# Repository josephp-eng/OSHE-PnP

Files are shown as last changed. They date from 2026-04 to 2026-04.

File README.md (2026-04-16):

# OSHE Pick and Place (V2.0)





<div align="center">

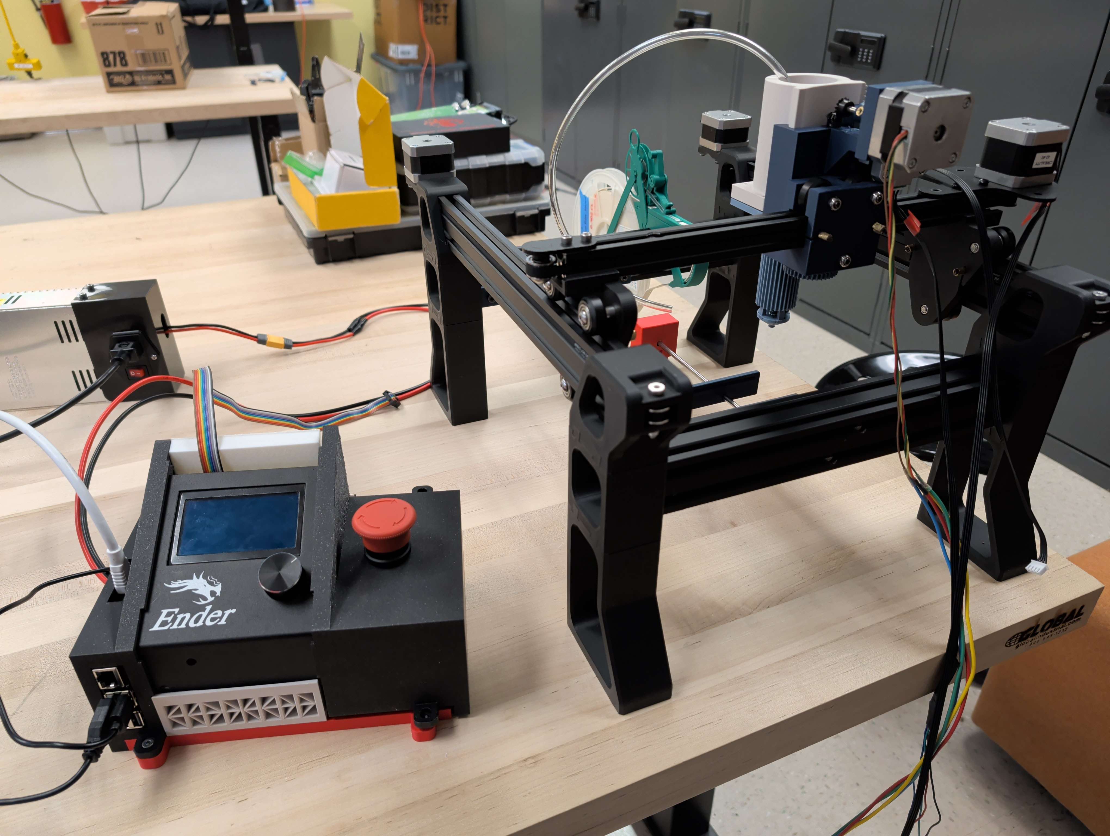
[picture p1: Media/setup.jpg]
Physical Model


</div>

## 🎯 Summary

The **OSHE Pick-and-Place** is a low-cost, open-source automated PCB assembly system developed at Michigan Technological University. While industrial SMT solutions are often financially out of reach for small labs and hobbyists, this project provides a modular, 3D-printable framework optimized for performance and ease of assembly. 

The system leverages the mechanical foundations of a Creality Ender 3, extending its capabilities into a dedicated manufacturing tool. By utilizing a vacuum-based toolhead and precision motion control, this project bridges the gap between manual prototyping and industrial production.

### 🛠️ Core Technical Achievements
* **Precision Motion Control:** Migrated to **Klipper Firmware** via Mainsail OS, allowing for higher-speed pathing and web-based machine management.
* **Advanced Toolhead Design:** A custom-engineered 3D-printed assembly featuring full 360° rotation and an integrated vacuum pick system.
* **Expanded Work Envelope:** Features a 370 x 480 mm footprint and support for PCBs up to 250 x 250 mm.
* **Safety-First Integration:** Adheres to **ISO-12100 standards**, featuring dedicated emergency stop (E-Stop) hardware and passive shielding.

### 📈 Current Project Status
The Spring 2026 revision (V2.0) has successfully transitioned the project into a functional integration phase. The machine currently supports SMD components (0804 and larger). Future development focuses on integrating computer vision and automated reel loading.
This project currently exists separately from the OpenPnP architecture. It was not designed around their software suite.

---

## 📂 Project Documentation

> [!IMPORTANT]
> For the complete technical breakdown, including assembly guides and safety protocols, refer to the full master document below.

* **[📄 Full Technical Manual](https://docs.google.com/document/d/1zdPMhOE8R7Szz68Ky9EoDyxVyp7iftD7q8Uco1WKPY8/edit?usp=sharing)** - Detailed assembly, electrical, and safety documentation.
* **[📦 Bill of Materials (BOM)](https://docs.google.com/spreadsheets/d/12Wk4rjcJYJA1_MIOu3757zk9U3lGuzmtH0hi1Tlr5gI/edit?usp=sharing)** - Comprehensive Google Spreadsheet lists of hardware, electronics, and 3D-printed parts.
* **[⚙️ Configuration Files](Software/Klipper)** - `printer.cfg` and macro definitions for Klipper.
* **[📐 CAD & Model Files](CAD)** - Full assembly models and printable components.

---

## 📋 Repository Structure
* `/CAD`: STEP and STL files for the machine and custom components.
* `/Software`: Klipper configurations and legacy Marlin firmware.
* `/Archive`: Legacy V1 designs and research notes.
* `/Media`: Renders and isometric views of models.
* `/BOMs`: Subsystem bills of materials, including hardware and 3D printed components.

## 💻 Getting Started
1. Review the [Our Documentation](https://docs.google.com/document/d/1zdPMhOE8R7Szz68Ky9EoDyxVyp7iftD7q8Uco1WKPY8/edit?usp=sharing) for the full build guide. Follow along with the 3D printing settings outlined in [CAD]([link](https://github.com/OSHE-Github/OSHE-PnP/tree/main/CAD))
2. Clone this repo to access the latest Klipper `printer.cfg`.
3. Join the conversation on the [OSHE Website]([link](https://oshe.io/)) and check out other OSHE projects at our [enterprise GitHub](https://github.com/OSHE-Github)

---
*Developed under the Michigan Technological University Open Source Hardware Enterprise (OSHE)*

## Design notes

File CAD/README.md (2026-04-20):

# Pick and Place CAD Documentation

<div align="center">

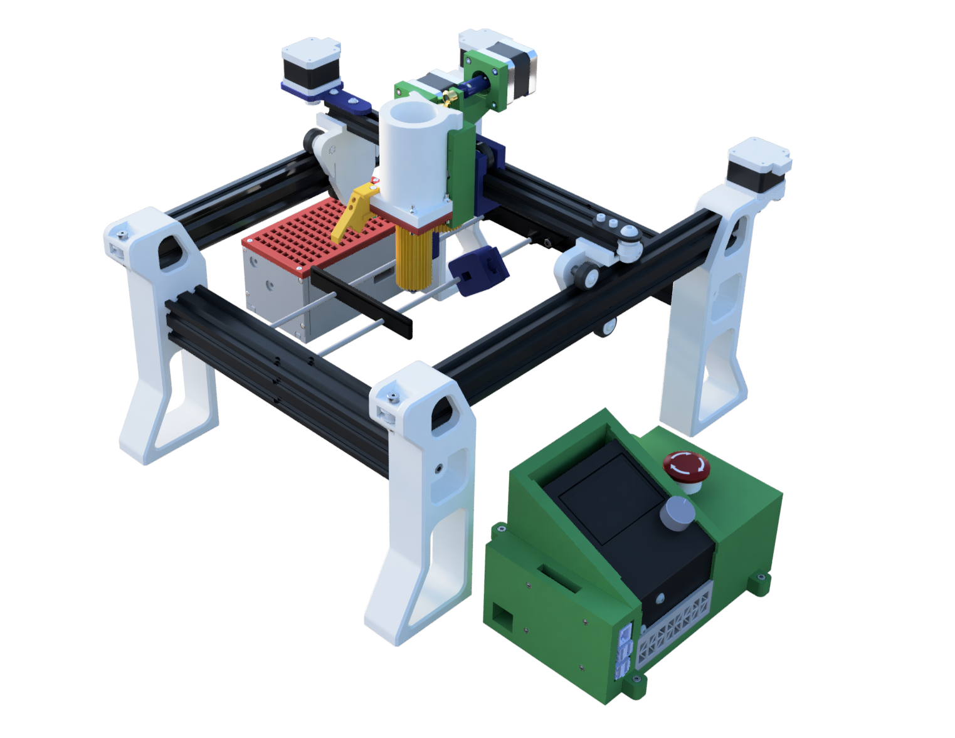
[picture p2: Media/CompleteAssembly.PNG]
Complete Assembly V2


</div>

This directory contains all mechanical design files for the OSHE Pick and Place project.

Each subsystem is organized in the preceding folders. Various STL and STEP files are available here for the current version of the pick-and-place machine.
Our system includes a nearly fully 3D-printable toolhead, base structures, PCB clamping, pneumatic and electrical enclosures, and a modified Push Pull Feeder from Mark Maker.

## Folder Structure
* **/V1-Legacy**: Baseline Ender 3 conversion (Fall 2025).
* **/V2-Active**: Current Klipper-integrated development (Spring 2026).
* `Ender-3-Full-Assembly.step`: Reference model for Ender 3 3D printer.

## Design Environment
* Autodesk Fusion 360 and Solidworks are used for modeling and integration
* All components exported to `.step` and `.stl`

## V2 Directory
* **/AxisSupport**: Supporting pieces for rolling the Y-axis along the X-axis
    * `YAxisSupportA.step`: Mounts the Y-axis with rollers, featuring an end stop for alignment, for the side of the Y-motor (print one)
    * `YAxisSupportB.step`: Mounts the Y-axis with rollers openly (print one)
* **/Clamping**: PCB Clamping mechanism
    * `ClampingAssembly.step`: Reference assembly of the clamp
    * `clampMount.step`, `clamp.step`, and `clampMountMirror.step`: Extrusion attachments for mount and clamping piece (print one of each)
    * `THandle.step`, `TSlotShaftCollar.step`, and `TSlotSpacer.step`: Printable clamping components to tension PCB. Print two of each, acquiring two compression springs.
* **/ElectricalEnclosure**: Housing for control board, Raspberry Pi, etc
    * `EncAssembly.step`: Reference assembly of constructed enclosure
    * Print one of each component in this folder. We utilized an Ender 3 fan and installed it on the back piece
* **/Framing**: The PnP structure and axis mounts
    * `BOT_leg.step` and `BOT_leg_MIRROR.step`: Print two of each to build idler, motor, mirrored idler, and mirrored motor structures, standard length
    * `MID_leg.step`: Print four of these for each of the four structure assemblies
    * `TOP_idler.step` and `TOP_idler_MIRROR.step`: Print one of each for the regular idler mount and mirrored idler structure
    * `TOP_motor.step` and `TOP_motor_MIRROR.step`: Print one of each for the regular motor mount and mirrored motor structure
    * *OPTIONALLY* `BOT_leg_LP.step` and `BOT_leg_LP_MIRROR.step`:  Alternative leg models for a lower profile, shorter machine
* **/PneumaticEnclosure**: Housing for vacuum pump and solenoid
    * `BackFrontPanel.step`: Print two of these for the front and back sides
    * `Baseplate.step`: Print one to build the base of the enclosure
    * `Sidepanel.step`: Print two of these for the smallest sides of the enclosure
    * `Top.step`: Print one of these for the top of the enclosure
* **/PushPullFeeder**: The Mark Maker, fully 3D printed tape and reel feeder (PETG)
    * `PushPullFeeder1.stl` and `PushPullFeeder2.stl`: Phase 1 and phase 2 of printing the feeder
    * `PushPullFeeder.scad`: The base code for the OpenSCAD model, venture if you dare
* **/ToolHead**: Nearly fully 3D printable toolhead with Z rotation
    * Print one of everything here
    * Supports are absolutely necessary for many components
    * `Prongs.step`: Print four of each of these for the 3D printed nozzle support, recommended in PETG for flexure
    * `Tool_Head_Assembly.step`: Reference assembly of constructed toolhead
* `PnP_Full_Assembly_V2.step`: **Master File** 

## Hardware Attribution
We utilize and build upon the work of the open-source community:
* **Push-Pull Feeder:** Designed by **Mark Maker**.
    * [Original Repository](https://github.com/markmaker/PushPullFeeder)
    * Our implementation includes optimization for use with 4040 v-slotted aluminum extrusion (commonly found on Ender 3), found in `/V2-Active/PushPullFeeder`.
    * This feeder is pretty unreliable, and in our testing, we struggled to have it operate consistently with our current modifications.

## Fabrication Guide
* **Material:** PETG (Motor mounts, Push Pull Feeder, Structural), PLA (Toolhead, PCB Clamping, Enclosures)
*Our Pick and Place structures can be printed in either PETG or PLA, but PETG is preferred*
* **Minimal Settings:** 0.2mm layer height, 2+ perimeters, 12% Gyroid infill, tree supports recommended
*The Push Pull Feeder is recommended by Mark Maker to be printed with more specific settings. See the attributed repository for more information.*
* **Hardware:** Our compoennts were printed and verified across the **Bambu Lab A1** and **Prusa Core 1** platforms with their respective slicers.
    * Standard 0.4mm nozzle recommended

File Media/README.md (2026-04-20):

## 🛠️ Assembly Gallery

| Component Focus | Snapshot | Key Detail |
| :--- | :---: | :--- |
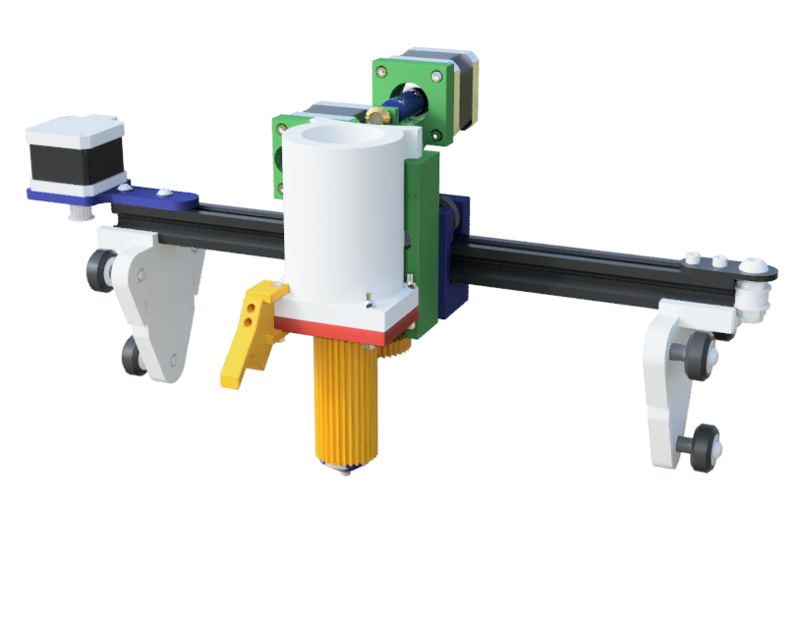
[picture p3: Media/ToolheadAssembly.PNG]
| **Tool Head** |  | Fully 3D-printable supporting 4-axes |
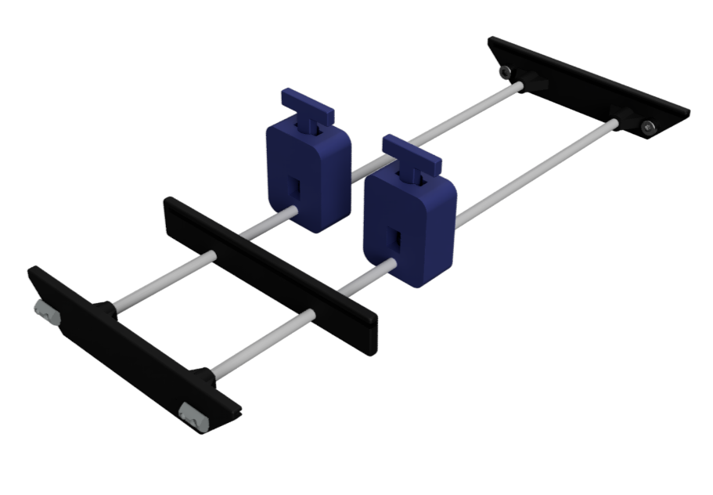
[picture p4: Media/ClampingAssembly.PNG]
| **Clamping** |  | PCB securing, fully 3D printed clamping mechanism, fitting within T-slots |
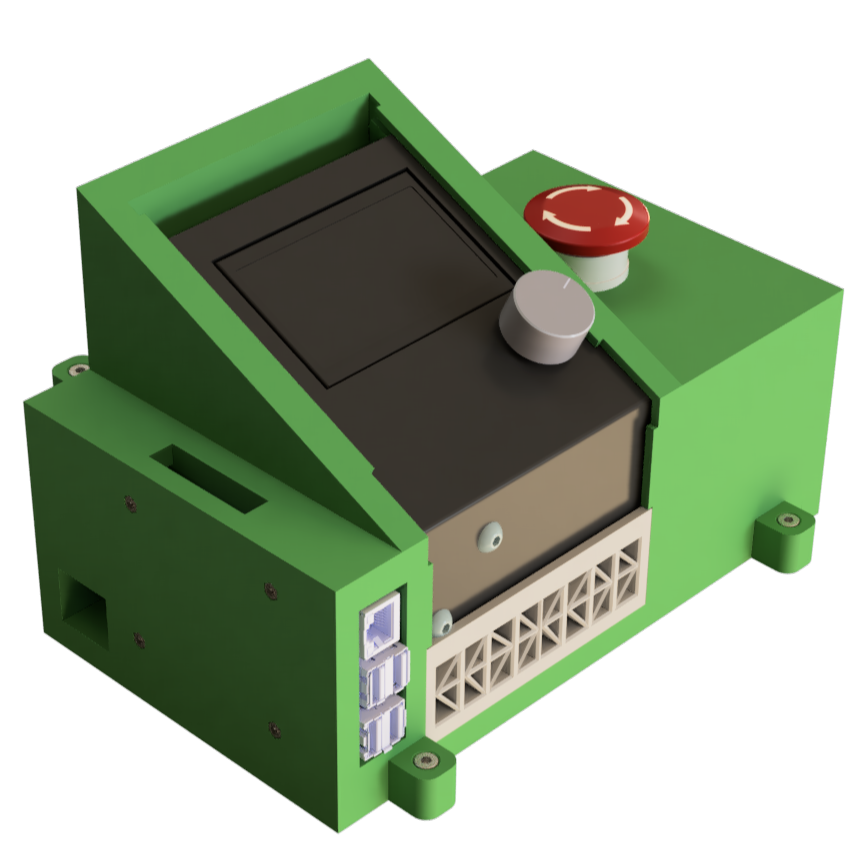
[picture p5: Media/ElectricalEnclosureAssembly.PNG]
| **Electrical Enclosure** |  | The brains; houses Pi 5 & OctoPro |
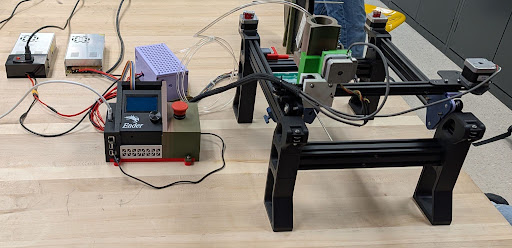
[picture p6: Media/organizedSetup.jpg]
| **Organized Setup** |  | Real-life build |
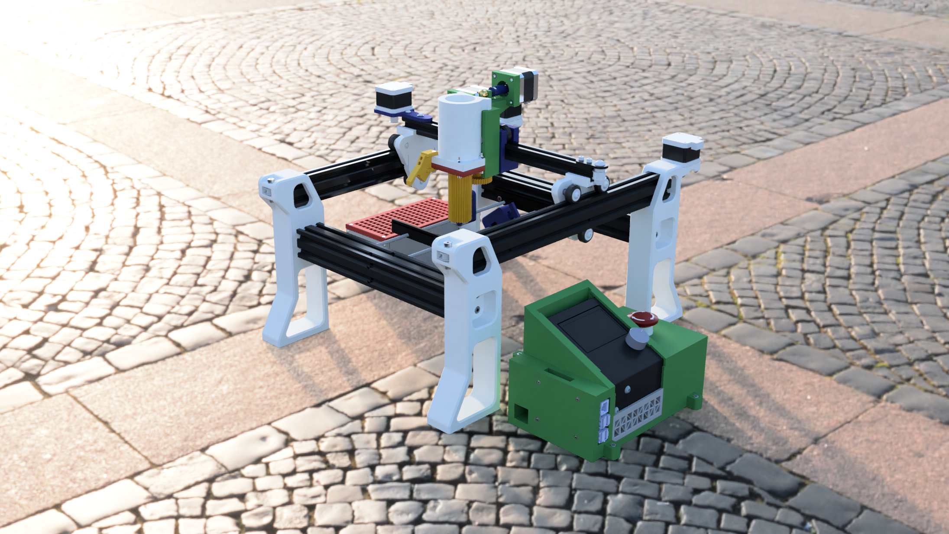
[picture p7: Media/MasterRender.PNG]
| **Master Shot** |  | Render shot complete with every subassembly |

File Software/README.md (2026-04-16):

# 💻 Software & Firmware Configuration

## Overview
The OSHE Pick-and-Place machine uses a modern 3D-printer software stack to manage high-precision motion control, vacuum actuation, and component indexing. 

As of **Version 2.0 (Spring 2026)**, the project has transitioned to **Klipper Firmware** managed via the **Mainsail** web interface. This configuration allows for real-time macro editing and superior hardware communication compared to traditional monolithic firmware.

---

## 🚀 The Klipper Stack (Recommended)
This is the current standard for the MTU-OSHE Pick-and-Place. It splits processing between a host computer (Raspberry Pi/PC) and the MCU (Octopro Control Board).

### 1. Host Interface: MainsailOS
* **Purpose:** Provides the web dashboard for machine operation.
* **Access:** Once installed, the machine is controlled via a local IP address in any web browser.

### 2. Control Logic: Custom Macros
The software includes specialized G-Code macros designed specifically for SMT assembly rather than 3D printing. These are located in `printer.cfg` and `macros.cfg`.
* **Spool Management:** Automated coordinate calculation for up to 5 component feeders.
* **Safety Logic:** Pre-configured "Z-Safe" heights to ensure the toolhead clears feeders and PCB clamps during rapid XY moves.
* **Vacuum Actuation:** Dedicated pin-mapping for the solenoid valve, allowing for `VACUUM_ON` and `VACUUM_OFF` commands.

### 3. Setup Instructions
1. **Flash MCU:** Use the provided Klipper firmware bin for your specific board (e.g., Creality V4.2.2 or SKR Mini).
2. **Configuration:** Upload the `printer.cfg` from this repository to your Mainsail config directory.
3. **Calibration:** Perform the **Machine Setup** and **Vacuum Calibration** steps detailed in the [Master Documentation](https://docs.google.com/document/d/1zdPMhOE8R7Szz68Ky9EoDyxVyp7iftD7q8Uco1WKPY8/edit?usp=sharing).

---

## ⚠️ Legacy: Marlin Firmware (Deprecated)
*Version 1.0 (Fall 2025) utilized Marlin. While instructions for this remain in the documentation for users with stock Ender 3 hardware, it is **not recommended** for V2.0 builds due to limitations in macro flexibility and real-time adjustment.*

## 🔍 Troubleshooting
* **TMC Driver Communication:** If all registers read zero, verify the 24V power supply to the board; Klipper will report a "Communication Failure" if the drivers are unpowered.
* **Vacuum Failure:** If the solenoid clicks but no suction occurs, check for air leaks in the 3D-printed toolhead manifold or verify the 24V-to-12V buck converter output.

---
*Refer to the Technical Information section (Page 55+) of the [Master Documentation](https://docs.google.com/document/d/1zdPMhOE8R7Szz68Ky9EoDyxVyp7iftD7q8Uco1WKPY8/edit?usp=sharing) for deep-dive code logic and coordinate offsets.*

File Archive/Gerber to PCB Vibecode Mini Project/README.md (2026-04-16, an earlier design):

# 🗄️ Archive: Gerber-to-GCode Utility

## Overview
This directory contains legacy software tools utilized during the early development phases (V1.0) of the OSHE Pick-and-Place project. 

### 🛠️ Gerber-to-GCode (HTML/JS)
This is a lightweight, browser-based utility designed to convert PCB Gerber files into machine-readable G-Code. 

* **Function:** It parses the aperture and coordinate data from Gerber files to generate toolpaths for component placement or basic PCB isolation milling.
* **Usage:** Open the `index.html` file in any modern web browser to access the interface.
* **Status:** **Legacy / Unmaintained.**
## ⚠️ Why is this archived?
As the project transitioned to **Version 2.0 (Spring 2026)**, the workflow shifted toward integrated coordinate exports from EDA software (like KiCad) and sophisticated Klipper macros. While this tool remains functional for basic conversions, it does not support the advanced safety checks, variable spool offsets, or vacuum logic found in the current V2.0 software stack.

## 📂 Contents
* `index.html`: The main user interface and logic engine.

---
*Note: This code is provided as-is for historical reference and is released under the same GNU GPL license as the main project.*

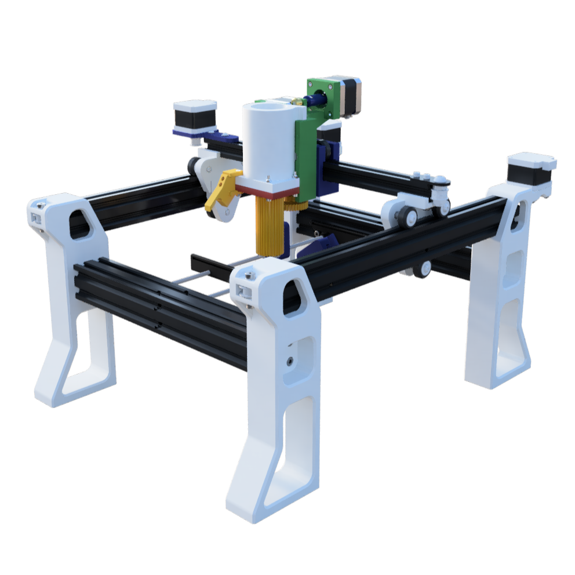
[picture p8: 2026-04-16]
Media/SquareRender.PNG

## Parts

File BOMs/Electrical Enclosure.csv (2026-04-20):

# | Part Name | Qty.
1 | Enclosure Left | 1
2 | Enclosure Right | 1
3 | Enclosure Bottom | 1
4 | Enclosure Back | 1
5 | Enclosure Vent | 1
6 | Raspberry Pi 5 | 1
7 | OctoPro V1 Control Board | 1
8 | Ender 3 HMI | 1
9 | Emergency Stop Button | 1
10 | 40mm 5V Ender 3 Fan | 1
11 | M3 x 16mm Socket Head Bolt | 8
12 | M2.5 x 10mm Socket Head Bolt | 4
13 | M4 x 8mm Socket Head Bolt | 2
14 | M4 x 10mm Socket Head Bolt | 4
15 | M4 Hexagon Nut | 6
16 | M3 Hexagon Nut | 8
17 | M2.5 Hexagon Nut | 4

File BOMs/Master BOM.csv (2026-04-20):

# | Part Name | Qty | Used In
1 | Aluminum Extrusion 4040 - 290mm | 2 | Frame Assembly
2 | Aluminum Extrusion 2040 - 400mm | 2 | Frame Assembly
3 | Aluminum Extrusion 2020 - 345mm | 1 | Frame, Y-Axis Assembly
4 | M5 x 45mm Screws / SHCS | 3 | Tool Head
5 | M5 x 30mm Pan Head Screws | 9 | Y-Axis Assembly
6 | M5 x 20mm Socket Head Bolts | 16 | Frame Assembly
7 | M5 x 16mm Socket Head Bolts | 4 | Frame Assembly
8 | M5 x 0.8 x 8mm Hex SHCS | 8 | PCB Clamps
9 | M5 T-Slot Nut | 2 | Y-Axis Assembly
10 | M5 T-Nuts | 8 | PCB Clamps
11 | M5 Self-Locking Nut / Lock Nut | 12 | Y-Axis (9), Tool Head (3)
12 | M4 x 10mm Socket Head Bolt | 4 | Electrical Enclosure
13 | M4 x 8mm Socket Head Bolt | 2 | Electrical Enclosure
14 | M4 x 16mm Button Head Bolt | 2 | Y-Axis Assembly
15 | M4 Hexagon Nut | 6 | Electrical Enclosure
16 | M4 Locknuts | 2 | Frame Assembly
17 | M4 T-Slot Nut | 2 | Y-Axis Assembly
18 | M3 x 16mm Socket Head Bolt | 8 | Electrical Enclosure
19 | M3 x 16mm Buttonhead Screws | 8 | Frame Assembly
20 | M3 x 8mm Screws | 20 | Pneumatic Enclosure
21 | M3 x 8mm Pan Head Screw | 4 | Electrical Enclosure (HMI)
22 | M3 x 6mm Screws | 8 | Tool Head
23 | M3 x 10mm Buttonhead Bolt | 4 | Y-Axis Assembly
24 | M3 x 15mm Screws | 2 | Tool Head
25 | M3 x 25mm Screws | 4 | Tool Head
26 | M3 Hexagon Nut / Nut | 12 | Electrical (8), Pneumatic (4)
27 | M3 Heat Set Inserts | 22 | Pneumatic (16), Tool Head (6)
28 | M3 Set Screw | 4 | Tool Head
29 | M2.5 x 10mm Socket Head Bolt | 4 | Electrical Enclosure
30 | M2.5 Hexagon Nut | 4 | Electrical Enclosure
31 | V-Slot / Ender 3 Rollers | 9 | Y-Axis Assembly
32 | Ender 3 Roller Spacers | 9 | Y-Axis Assembly
33 | NEMA 17 Stepper Motors | 5 | Frame (2), Tool Head (2), Y-Axis (1)
34 | E-Stop Button | 1 | Electrical Enclosure
35 | Vacuum Pump | 1 | Pneumatic Enclosure
36 | Solenoid Valve (NC) | 1 | Pneumatic Enclosure
37 | Raspberry Pi 5 | 1 | Electrical Enclosure
38 | OctoPro V1 Board | 1 | Electrical Enclosure

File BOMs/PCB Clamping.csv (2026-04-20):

# | Part Name | Qty.
1 | M5 x 0.8 x 8mm Hexagon Socket Head Cap Screws | 4
2 | M5 T-Nuts | 4
3 | M5 x 0.8 x 8mm Hexagon Socket Head Cap Screws | 4
4 | M5 T-Nuts | 4
5 | 5mm OD Rods | 2
6 | 3D Printed PCB Clamp Mounts | 2
7 | 3D Printed T-Slot Handle | 2
8 | 3D Printed T-Slot Handle Spacer | 2
9 | 3D Printed T-Slot Shaft Collar | 2
10 | 20mm long 5mm diameter Spring | 2-4
11 | 3D Printed Board Clamp | 1

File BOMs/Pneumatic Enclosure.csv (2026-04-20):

# | Part Name | Qty.
1 | M3 x 8mm Screws | 20
2 | M3 Heat Set Inserts | 16
3 | #8x0.5in Screws | 2
4 | Vacuum Pump | 1
5 | Direct Action NC Solenoid Valve | 1
6 | 3D Printed Top | 1
7 | 3D Printed Side Panel | 2
8 | 3D Printed Back Front Panel | 2
9 | 3D Printed Base Plate | 1
10 | 15cm Length of 6mm OD 4mm ID Pneumatic Tubing | 1
11 | 6mm 1/4in NPT pneumatic Fittings | 2
12 | M3 Nuts | 4

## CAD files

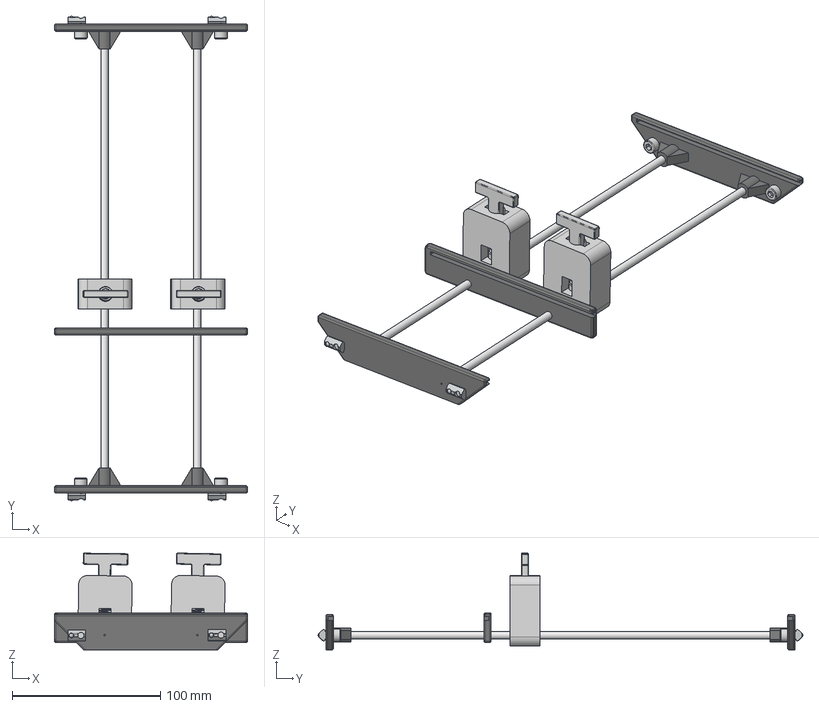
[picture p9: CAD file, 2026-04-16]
CAD/V2-Active/Clamping/ClampingAssembly.step
130.0 x 326.5 x 65.3 mm
mirrored
Rod x 2
TSlotShaftCollar x 2
TSlotSpacer x 2
THandle x 2
94125K614_Compression Springs x 2
ISO 4762 - M5 x 8 Steel 4.6 Plain x 4
Ball 20s x 4

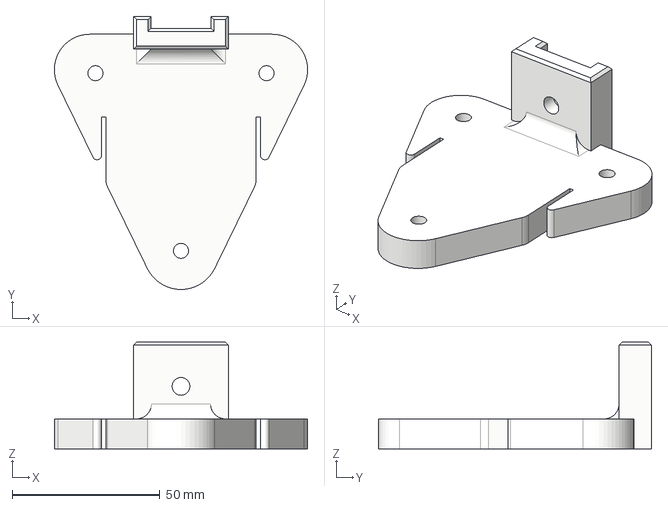
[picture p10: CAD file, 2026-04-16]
CAD/V2-Active/AxisSupport/YAxisSupportA.step
85.7 x 92.4 x 36.2 mm

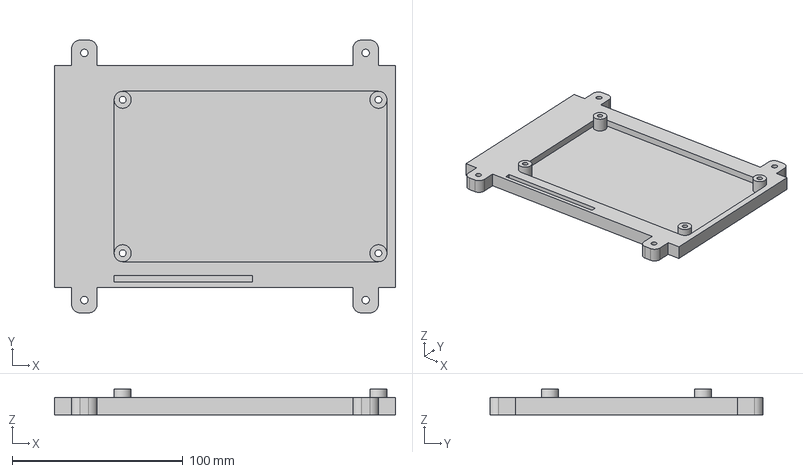
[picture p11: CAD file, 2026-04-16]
CAD/V2-Active/ElectricalEnclosure/Enc_Bot.step
200.0 x 160.0 x 15.0 mm

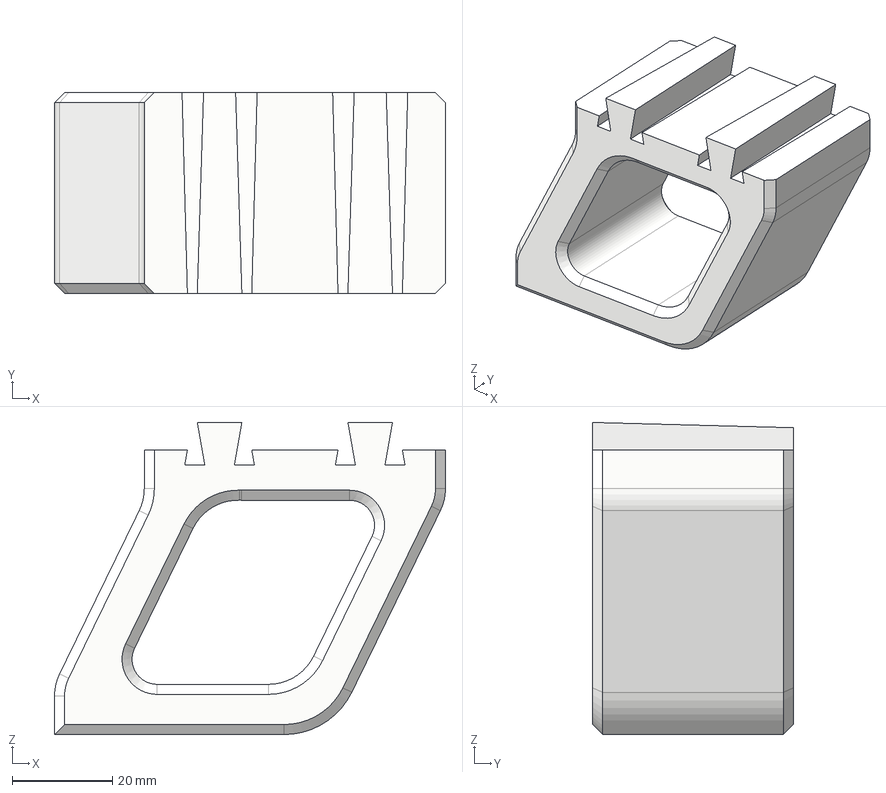
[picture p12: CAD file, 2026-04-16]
CAD/V2-Active/Framing/BOT_leg_LP.step
77.9 x 40.0 x 62.2 mm

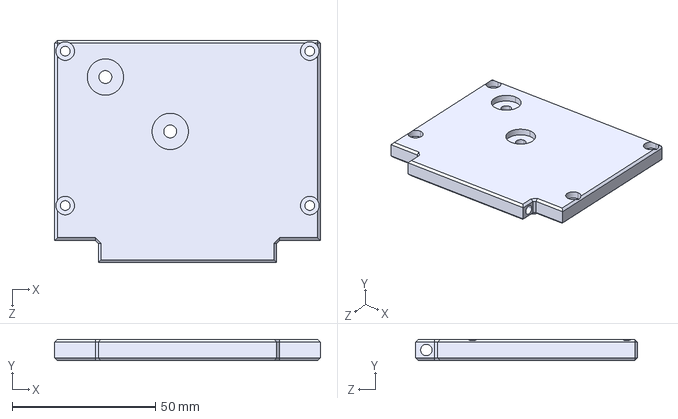
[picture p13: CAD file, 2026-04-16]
CAD/V2-Active/PneumaticEnclosure/Sidepanel.STEP
93.0 x 7.50 x 77.7 mm

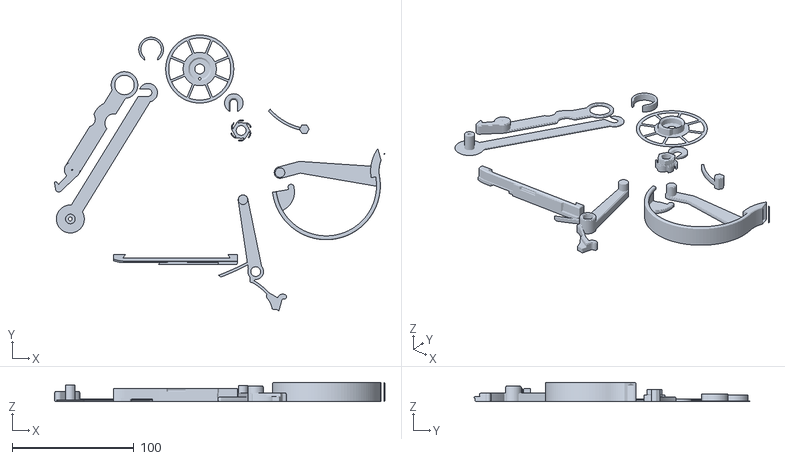
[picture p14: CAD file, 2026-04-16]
CAD/V2-Active/PushPullFeeder/PushPullFeeder2.stl
271.4 x 227.1 x 15.7

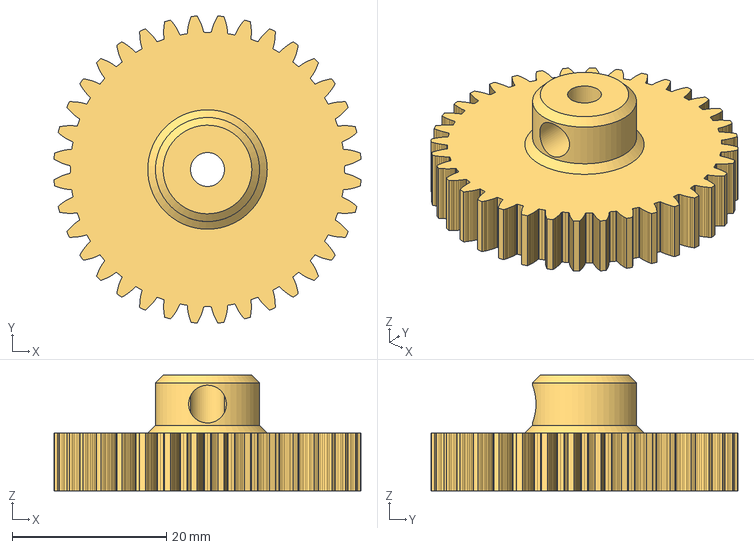
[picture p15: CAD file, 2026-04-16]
CAD/V2-Active/ToolHead/36Gear.step
39.8 x 39.8 x 15.0 mm

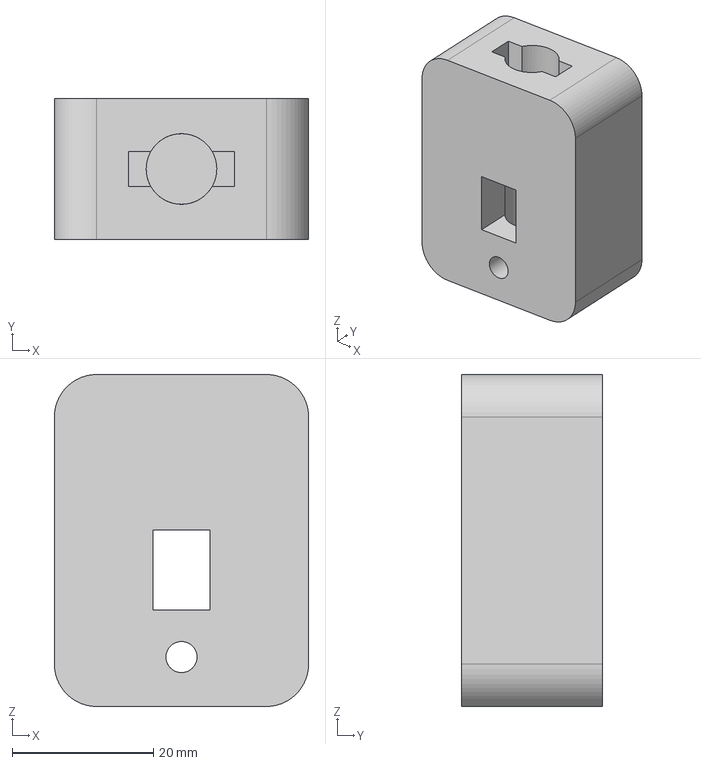
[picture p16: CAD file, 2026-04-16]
CAD/V2-Active/Clamping/TSlotShaftCollar.step
36.0 x 20.0 x 47.0 mm

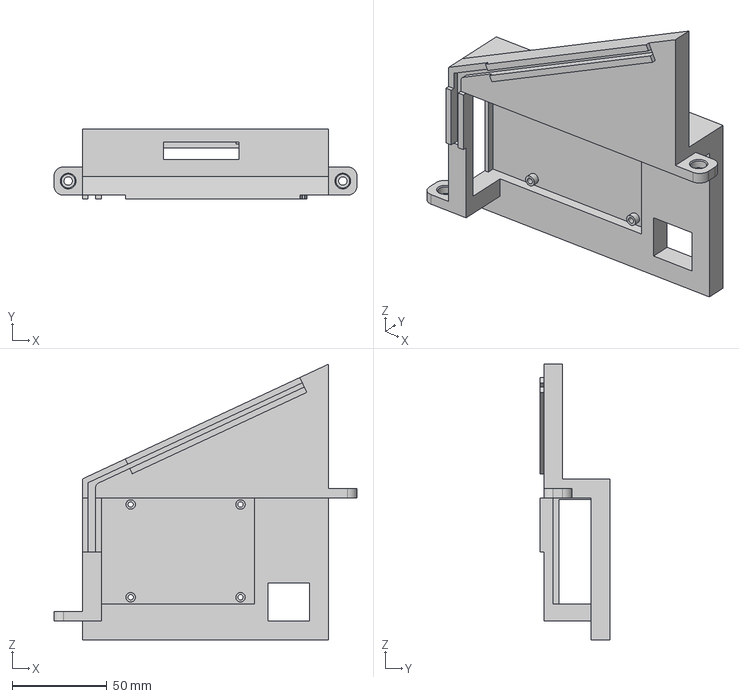
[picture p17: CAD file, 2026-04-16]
CAD/V2-Active/ElectricalEnclosure/Enc_Left.step
160.0 x 37.0 x 145.6 mm

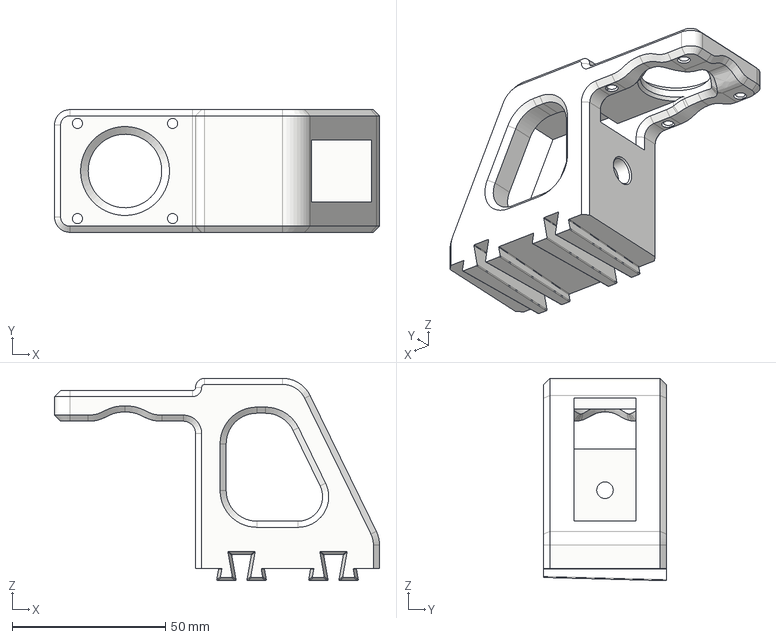
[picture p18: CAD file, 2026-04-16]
CAD/V2-Active/Framing/TOP_motor_MIRROR.step
106.0 x 40.0 x 66.0 mm

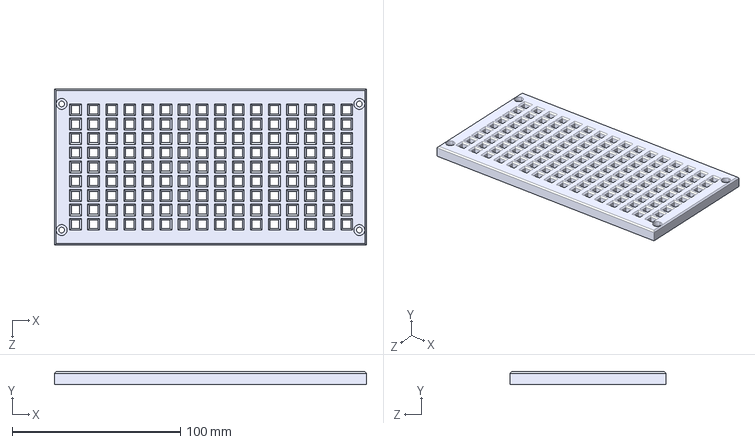
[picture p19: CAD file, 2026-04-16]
CAD/V2-Active/PneumaticEnclosure/Top.STEP
185.5 x 7.50 x 93.0 mm

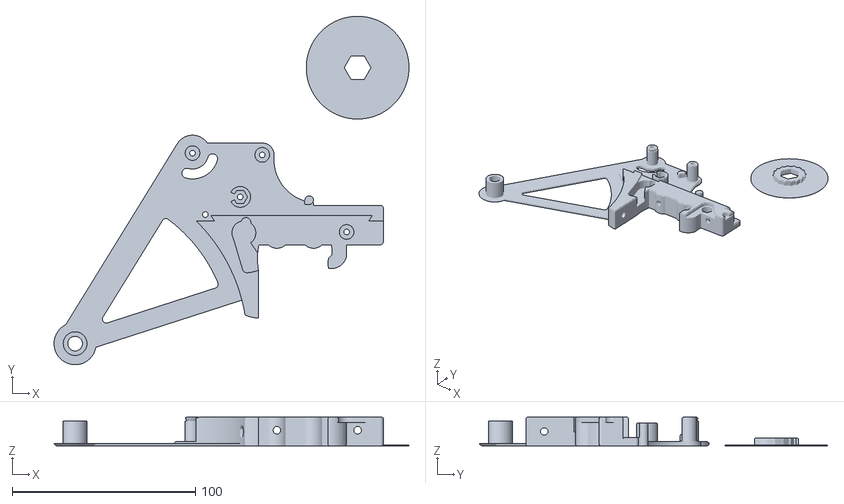
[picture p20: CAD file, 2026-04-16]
CAD/V2-Active/PushPullFeeder/PushPullFeeder1.stl
193.5 x 189.9 x 15.7

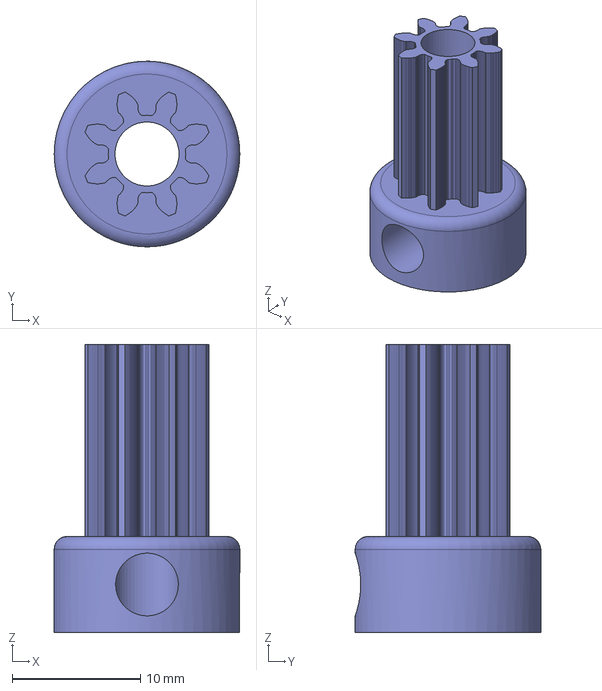
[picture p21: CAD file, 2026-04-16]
CAD/V2-Active/ToolHead/8Gear.step
14.5 x 14.5 x 22.5 mm

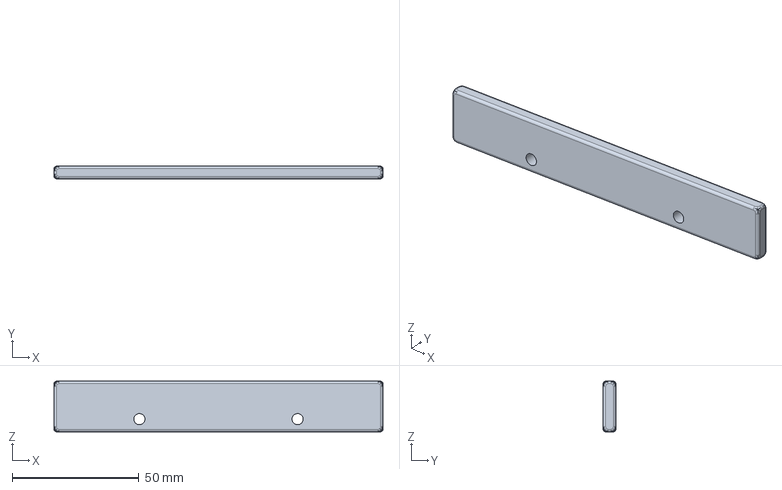
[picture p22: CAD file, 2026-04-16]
CAD/V2-Active/Clamping/clamp.step
130.0 x 5.00 x 20.0 mm

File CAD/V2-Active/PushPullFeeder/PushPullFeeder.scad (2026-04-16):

/*
 * Copyright (C) 2020 <mark@makr.zone>
 *
 * Inspired by Dining-Philosopher's Litefeeder
 * https://github.com/dining-philosopher/litefeeder
 * and Jed Smith's Litefeeder++ friction wheel
 * https://loonatec.com/pnp-semi-automatic-feeder/
 * 
 * The PushPullFeeder is free software: you can redistribute it and/or modify it under the terms of the GNU
 * General Public License as published by the Free Software Foundation, either version 3 of the
 * License, or (at your option) any later version.
 * 
 * The PushPullFeeder is distributed in the hope that it will be useful, but WITHOUT ANY WARRANTY; without even
 * the implied warranty of MERCHANTABILITY or FITNESS FOR A PARTICULAR PURPOSE. See the GNU General
 * Public License for more details.
 * 
 * You should have received a copy of the GNU General Public License along with OpenPnP. If not, see
 * <http://www.gnu.org/licenses/>.
 * 
 * For more information visit https://makr.zone/tag/feeder/
 */

/* [ Make Options ] */

// Single/special selection
option=-2; // [0:"* Individual switches (see below...)", -1:"* Phase I Parts", -2:"* Phase II Parts", -3:"* Everything", -4:"* Ratchet parts", 1:"Base plate", 2:"Lever", 3:"Spool, base", 4:"Spool, cover", 5:"Friction wheel", 6:"Tape inset", 7:"Ratchet blocking spring", 8:"Reel counterpart", 9:"Handle and lock", 10:"Liteplacer nozzle adapter", 11:"Liteplacer lever actuator", 12:"Spent Tape Chute", 13:"Test print"]

// Base plate of the feeder 
make_base_plate         = false;          //PH1
// Lever with the dog
make_lever              = true;         //PH2
// Spool left side (base), with ratchet wheel
make_spool_left        = false;           //PH1
// Spool right side (cover)
make_spool_right       = false;           //PH1
// Friction wheel, connecting the two spool halves with a slip-transmission
make_friction_wheel     = false;          //PH1
// Exchangable tape inset, allows to use different tape thickness/embossing
make_inset              = false;          //PH1
// Spring blocking the ratchet from going in reverse
make_blocking_spring    = false;          //PH1
// Reel holder counterpart holding the reel up on the other side (for narrow reels only)
make_reel_counterpart   = false;          //PH1
// Handle and lock for the extrusion mount
make_handle_lock        = false;          //PH1
// Liteplacer specific nozzle adapter
make_nozzle_adapter     = false;        
// Liteplacer specific lever actuator
make_lever_actuator     = false;
// Simple spent tape chute
make_tape_chute         = true;         //PH2

// Test print
make_test_print         = false;

phase1 = (option == -1);
phase2 = (option == -2);
everything = (option == -3);
ratchet_parts = (option == -4);

do_base_plate         = (option == 0 && make_base_plate)         || (option ==  1)  || everything || phase1 || ratchet_parts;
do_lever              = (option == 0 && make_lever)              || (option ==  2)  || everything || phase2 || ratchet_parts;
do_spool_left         = (option == 0 && make_spool_left)         || (option ==  3)  || everything || phase1 || ratchet_parts;
do_spool_right        = (option == 0 && make_spool_right)        || (option ==  4)  || everything || phase2;
do_friction_wheel     = (option == 0 && make_friction_wheel)     || (option ==  5)  || everything || phase2;
do_inset              = (option == 0 && make_inset)              || (option ==  6)  || everything || phase2;
do_blocking_spring    = (option == 0 && make_blocking_spring)    || (option ==  7)  || everything || phase2 || ratchet_parts;
do_reel_counterpart   = (option == 0 && make_reel_counterpart)   || (option ==  8)  || everything || phase2;
do_handle_lock        = (option == 0 && make_handle_lock)        || (option ==  9)  || everything || phase2;
do_nozzle_adapter     = (option == 0 && make_nozzle_adapter)     || (option ==  10) || everything;
do_lever_actuator     = (option == 0 && make_lever_actuator)     || (option ==  11) || everything;
do_tape_chute         = (option == 0 && make_tape_chute)         || (option ==  12) || everything || phase2;
do_test_print         = (option == 0 && make_test_print)         || (option ==  13);

debug_ratchet = ratchet_parts;

/* [ Logo and Text ] */

// Switch on/off logos and text (except tag)
logo_enabled=false;
// Logo text to be printed on the reverse of the base plate
logo_text="";
// Tag to be printed on the reverse of the base plate (revision number etc.)
logo_tag="408";
// Open Source Hardware Logo size (set 0 to switch off)
logo_size=0; 
// Etching depth
logo_etch=0.0; 
// Logo outline pen width
logo_etch_pen=0.8; // [0.2:0.01:2]
// Additional font weight
logo_etch_font=0.2; // [-0.5:0.01:1]
// Logo position in x
logo_x=-60;
// Logo position in y
logo_y=24;
// Text position in x
logo_text_x=-60;
// Text position in x
logo_text_y=10;
// Tag position in x
logo_tag_x=-22;
// Tag position in y
logo_tag_y=-4.5;
// Logo_font 
//logo_font="Electrolize:style=Regular"; // ["Electrolize:style=Regular", "Liberation Mono:style=Bold"]
//use <Electrolize-Regular.ttf>
// Electrolize-Regular.ttf: Copyright (c) 2011, Cyreal (www.cyreal.org) 
// with Reserved Font Name "Electrolize" This Font Software is licensed 
// under the SIL Open Font License, Version 1.1. This license is available 
// with a FAQ at: http://scripts.sil.org/OFL
// https://github.com/google/fonts/tree/master/ofl/electrolize

// Text font size
logo_font_size=5.4;
//logo_tag_font=logo_font;
// Tag font size
logo_tag_font_size=4.6;

/* [ Display ] */

// Arrange the parts as assembled
debug=false;
// Relax the springs in assembled mode
relax_springs=false;
// Render some complex bodies in preview (better quality, slower rendering)
preview_rendering=false;
// Litefeeder reference (from: https://github.com/dining-philosopher/litefeeder)
do_litefeeder=false;


/*  [ 3D Printing ] */

// Standard layer height
layer_height=0.3;
// Standard extrusion width
extrusion_width=0.42;
// Minimum gap between parts on the the print bed
gap=2;
// Maximum spacing between supports (0 to switch off)
support_grid=0;

// General play rationale: 
// the play is modelled on the smaller, removable part, so you can tune it with quick re-prints.

// Play between parts that need to snap-in (empirical)
play=0.05; 
// Play on axles (empirical)
axle_play=0.02;

// Play on the spool axle 
spool_axle_play=axle_play;
// Specific snap-in play for inset 
inset_play=play;
// Play on the handle lock
handle_lock_play=play;
// Play on fixtures
fixture_play=play; 

// Minimal sturdy vertical wall 
wall_strength_min=1.3;
// Round up to nearest multiple of extrusion width
wall=ceil(wall_strength_min/extrusion_width)*extrusion_width;
// Minimal sturdy horizontal wall 
layered_wall_strength_min=0.5;
// Round up to nearest multiple of layer height
layer_wall=ceil(layered_wall_strength_min/layer_height)*layer_height;
// bevel/rounding in X/Y
bevel_xy=wall;
// bevel in Z
bevel_z=2*layer_height;

// Maximum allowed error in (most) curve approximations
_fp=0.02; // $fn is determined by this maximum error 
// Epsilon for CSG body overlap
e=0.02;
$fs=extrusion_width;


/* [ Tape Specification ] */

// Tape width
tape_width=8; // [8:4:24]
// Tape width adjustment for inset.
tape_width_adjust=0.0; // [-0.25:0.01:0.25]
tape_width_eff=tape_width+tape_width_adjust;
// Tape thickness (not incuding the embossed pockets)
tape_thickness=1.2; // [0:0.01:1.5]
// Embossed pockets portruding from the underside of the tape
tape_emboss=0; // [0:0.01:2.4] 
    // 250V cap = 1.6
// Embossed pockets size, across tape, measured outside (underside of tape)
tape_emboss_size=3.75; 


/* [ Tape Specification, Advanced ] */

// Maximum overall tape height for exchangeable insets (should not change)
tape_max_height=4;
// Maximum delta from tape width to reel width (from EIA 481, do not change)
tape_reel_max_width_delta=6.4; 
// Sprocket hole diameter (should not change)
sprocket_hole_diameter=1.5;
// Sprocket hole distance from tape edge (should not change)
sprocket_hole_distance=1.75;
sprocket_hole_margin=sprocket_hole_distance-sprocket_hole_diameter/2;
// Sprocket hole pitch (should not change)
sprocket_pitch=4; 
// maximum sprocket side gap to cover tape
sprocket_gap=sprocket_hole_distance+sprocket_hole_diameter/2;  
// Minimum margin where cover tape is attached
tape_min_margin=0.6; 
sprocket_margin=sprocket_gap+tape_min_margin;

/* [ Tape Inset ] */
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

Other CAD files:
CAD/V2-Active/AxisSupport/YAxisSupportB.step
CAD/V2-Active/ElectricalEnclosure/Enc_Right.step
CAD/V2-Active/Framing/TOP_idler_MIRROR.step
CAD/V2-Active/PneumaticEnclosure/Baseplate.STEP
CAD/V1-Legacy/Print/PushPullFeeder.scad
CAD/V1-Legacy/Print/Base Structures/IdlerStruct.step
CAD/V1-Legacy/Print/Base Structures/IdlerStructMirror.step
CAD/V1-Legacy/Print/Base Structures/MotorStruct.step
CAD/V1-Legacy/Print/Base Structures/MotorStructMirror.step
CAD/V1-Legacy/Print/Ender-3_Display_Cover_factory_srews_with_bell_closed_3connectors.STL
CAD/V1-Legacy/Print/PCB Mount/Clamps1.step
CAD/V1-Legacy/Print/PCB Mount/Clamps2.step
CAD/V1-Legacy/Print/PCB Mount/RodHolderPlateShort.STEP
CAD/V1-Legacy/Print/PushPullFeeder/PushPullFeeder_PH1.stl
CAD/V1-Legacy/Print/PushPullFeeder/PushPullFeeder_PH2.stl
CAD/V1-Legacy/Print/Tool Head/Adapter.STL
CAD/V1-Legacy/Print/Tool Head/BasePlate.STL
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

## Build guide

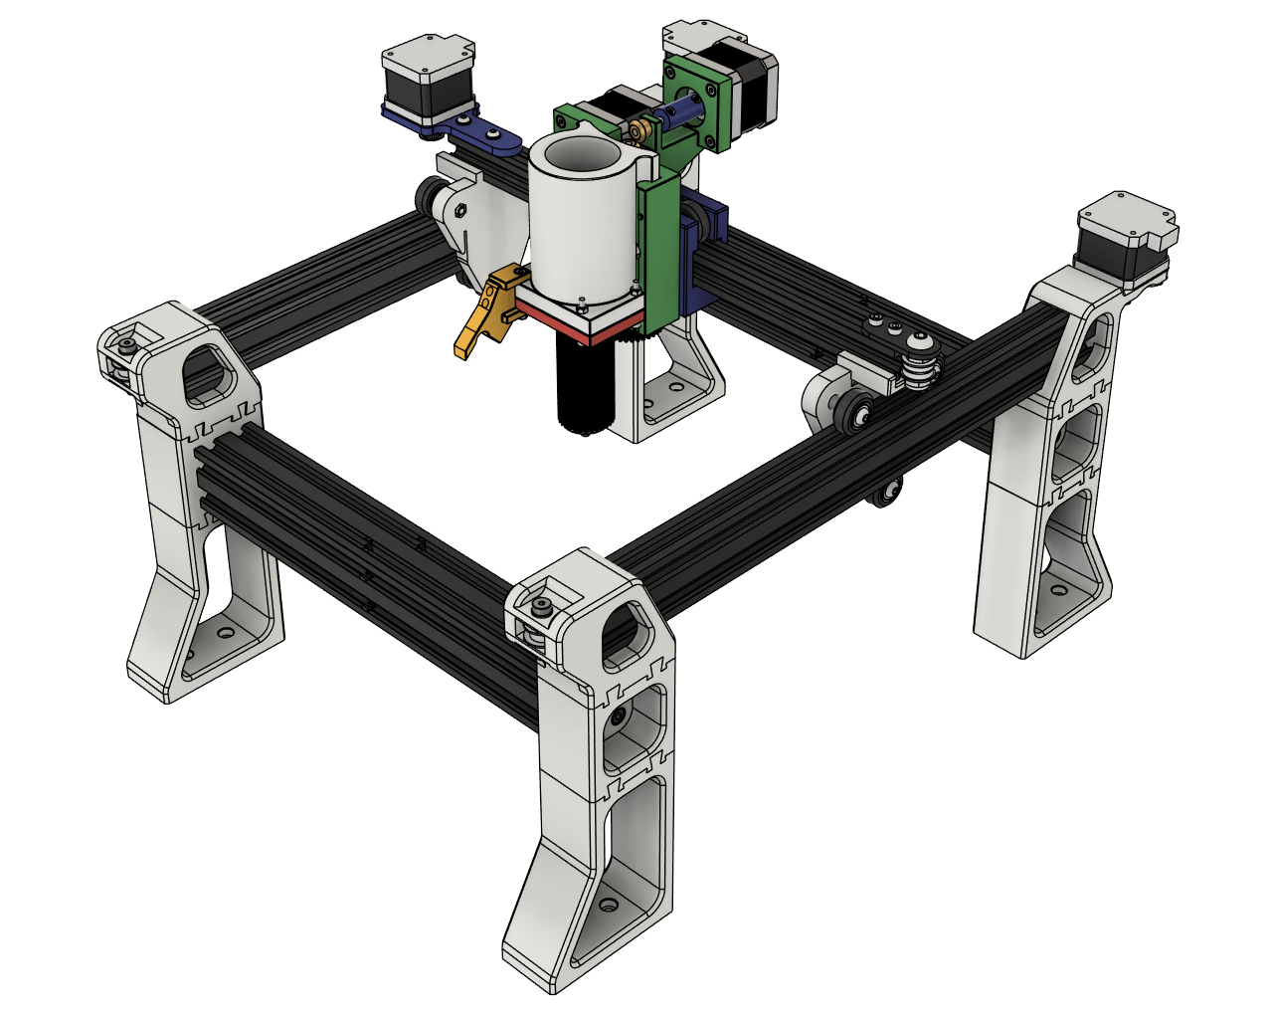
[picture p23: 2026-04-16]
Media/StructureAssembly.png

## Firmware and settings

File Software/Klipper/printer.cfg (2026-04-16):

# ============================================================
# PICK AND PLACE MACHINE - KLIPPER CONFIG
# Ender 3 Mechanics + Octopus Pro + TMC5160T Drivers
# Raspberry Pi 5 Host
# ============================================================

###############################
#Printer Config
###############################

[include mainsail.cfg]

[mcu]
serial: /dev/serial/by-id/usb-Klipper_stm32h723xx_280028000751313339373836-if00

[printer]
kinematics: cartesian
max_velocity: 400
max_accel: 3000
square_corner_velocity: 5.0
max_z_velocity: 200
max_z_accel: 3000

[force_move]
enable_force_move: True

[include moonraker_obico_macros.cfg]

[fan]
pin: PA8
max_power: 1.0

[board_pins]
aliases:
    EXP1_1=PE8, EXP1_2=PE7,
    EXP1_3=PE9, EXP1_4=PE10,
    EXP1_5=PE12, EXP1_6=PE13,
    EXP1_7=PE14, EXP1_8=PE15

[display]
lcd_type: st7920
cs_pin: EXP1_7
sclk_pin: EXP1_6
sid_pin: EXP1_8
encoder_pins: ^EXP1_5, ^EXP1_3
click_pin: ^!EXP1_2

[output_pin beeper]
pin: EXP1_1


###############################
#Steppers
###############################

#Stepper X
[stepper_x]
step_pin: PF13
dir_pin: PF12
enable_pin: !PF14
rotation_distance: 40
microsteps: 16
full_steps_per_rotation: 200
endstop_pin: tmc5160_stepper_x:virtual_endstop
position_min: -5
position_endstop: 0
position_max: 260
homing_speed: 40
homing_retract_dist: 0

[tmc5160 stepper_x]
cs_pin: PC4
spi_software_sclk_pin: PA5
spi_software_mosi_pin: PA7
spi_software_miso_pin: PA6
diag1_pin: ^!PG6
run_current: 0.800
stealthchop_threshold: 50
driver_SGT: 5
#2nd X Axis (X1)
[stepper_x1]
step_pin: PF9
dir_pin: !PF10
enable_pin: !PG2
rotation_distance: 40
microsteps: 16
full_steps_per_rotation: 200

[tmc5160 stepper_x1]
cs_pin: PF2
spi_software_sclk_pin: PA5
spi_software_mosi_pin: PA7
spi_software_miso_pin: PA6
run_current: 0.800
stealthchop_threshold: 50
#Stepper Y
[stepper_y]
step_pin: PG0
dir_pin: PG1
enable_pin: !PF15
rotation_distance: 40
microsteps: 16
full_steps_per_rotation: 200
endstop_pin: tmc5160_stepper_y:virtual_endstop
position_min: -5
position_endstop: 0
position_max: 195
homing_speed: 40
homing_retract_dist: 0

[tmc5160 stepper_y]
cs_pin: PD11
spi_software_sclk_pin: PA5
spi_software_mosi_pin: PA7
spi_software_miso_pin: PA6
diag1_pin: ^!PG9
run_current: 0.800
stealthchop_threshold: 50
driver_SGT: 1

#Stepper Z
[stepper_z]
step_pin: PF11
dir_pin: !PG3
enable_pin: !PG5
rotation_distance: 40
microsteps: 16
full_steps_per_rotation: 200
endstop_pin: tmc5160_stepper_z:virtual_endstop
position_endstop: 0
position_max: 80
homing_speed: 40
homing_retract_dist: 0

[tmc5160 stepper_z]
cs_pin: PC6
spi_software_sclk_pin: PA5
spi_software_mosi_pin: PA7
spi_software_miso_pin: PA6
diag1_pin: ^!PG10
run_current: 0.400
stealthchop_threshold: 50
driver_SGT: 4

# TOOLHEAD ROTATION
[manual_stepper toolhead_rotation]
step_pin: PG4
dir_pin: PC1
enable_pin: !PA2
microsteps: 16
rotation_distance: 360
gear_ratio: 36:30
full_steps_per_rotation: 200
velocity: 100
accel: 1000

[tmc5160 manual_stepper toolhead_rotation]
cs_pin: PC7
spi_software_sclk_pin: PA5
spi_software_mosi_pin: PA7
spi_software_miso_pin: PA6
run_current: 0.400
stealthchop_threshold: 0

###############################
#Macros
###############################
[homing_override]
axes: xyz
gcode:
    # Check which axes were explicitly requested (e.g., G28 X vs G28)
    {% set home_all = 'X' not in params and 'Y' not in params and 'Z' not in params %}
    
    # 1. Home Z, then move to a safe clearance height
    {% if home_all or 'Z' in params %}
        G28 Z
        # Moves Z to 99mm at 200mm/s (12000 mm/min)
        G1 Z80 F12000 
    {% endif %}
    
    # 2. Home Y
    {% if home_all or 'Y' in params %}
        G28 Y
        # Best practice for sensorless: back off the physical hard stop slightly
        G1 Y5 F1200
    {% endif %}
    
    # 3. Home X
    {% if home_all or 'X' in params %}
        G28 X
        # Best practice for sensorless: back off the physical hard stop slightly
        G1 X5 F1200
    {% endif %}
    
    # 4. Zero the Toolhead Rotation (C-Axis)
    {% if home_all %}
        # Instantly sets the current position of the manual stepper to 0
        MANUAL_STEPPER STEPPER=toolhead_rotation SET_POSITION=0
    {% endif %}

# VACUUM PUMP CONTROL
[output_pin vacuum_pump]
pin: PA1
value: 0
shutdown_value: 0

[gcode_macro PUMP_ON]
description: Turns on the vacuum pump
gcode:
    SET_PIN PIN=vacuum_pump VALUE=1

[gcode_macro PUMP_OFF]
description: Turns off the vacuum pump
gcode:
    SET_PIN PIN=vacuum_pump VALUE=0

[gcode_macro TOGGLE_PUMP]
description: Toggles the vacuum pump state (useful for physical buttons or web UI)
gcode:
    {% if printer['output_pin vacuum_pump'].value == 0 %}
        PUMP_ON
    {% else %}
        PUMP_OFF
    {% endif %}

# SOLENIOD CONTROL
[output_pin valve]
pin: PE5
value: 0
shutdown_value: 0

[gcode_macro VALVE_ON]
description: Opens the solenoid valve
gcode:
    SET_PIN PIN=valve VALUE=1

[gcode_macro VALVE_OFF]
description: Closes the solenoid valve
gcode:
    SET_PIN PIN=valve VALUE=0

[gcode_macro TOGGLE_VALVE]
description: Toggles the solenoid valve state
gcode:
    {% if printer['output_pin valve'].value == 0 %}
        VALVE_ON
    {% else %}
        VALVE_OFF
    {% endif %}

# PICK COMPONENT MACRO
[gcode_macro PICK]
description: Moves to a specified spool, lowers, grabs a component, and retracts.
gcode:
    # --- CONFIGURATION VARIABLES ---
    {% set base_x = 45.0 %}      # X coordinate of Spool 1
    {% set base_y = 190.0 %}     # Y coordinate of Spool 1
    
    # Set the offset depending on how your spools are lined up. 
    {% set offset_x = 0.0 %}    # Distance between each spool on the X axis
    {% set offset_y = 0.0 %}     # Distance between each spool on the Y axis
    
    {% set z_safe = 80.0 %}      # Safe Z height for travel to avoid collisions
    {% set z_pick = 66.0 %}       # Z height to touch the component
    
    {% set speed_xy = 9000 %}    # XY travel speed (mm/min)
    {% set speed_z = 6000 %}     # Z plunge/retract speed (mm/min)
    {% set dwell_time = 250 %}   # Time to wait for vacuum to build (milliseconds)
    
    # --- INPUT PARAMETER ---
    # Get the requested spool number from the command. Default to 1 if none provided.
    {% set spool_num = params.SPOOL|default(1)|int %}
    
    # --- SAFETY CHECK ---
    {% if spool_num < 1 or spool_num > 5 %}
        { action_raise_error("Invalid spool number! Must be between 1 and 5.") }
    {% else %}
        
        # --- CALCULATE TARGET COORDINATES ---
        # Subtract 1 from the spool number so Spool 1 multiplies the offset by 0
        {% set target_x = base_x + ((spool_num - 1) * offset_x) %}
        {% set target_y = base_y + ((spool_num - 1) * offset_y) %}
        
        G90 #Abs Positioning         
        G1 Z{z_safe} F{speed_z}       
        G1 X{base_x+25} F{speed_xy}
        # 2. Travel to the calculated XY position
        G1 Y{target_y} F{speed_xy}
        G1 X{target_x} F{speed_xy}  
        # 3. Lower Z to the pick height
        G1 Z{z_pick} F{speed_z}  
        # 4. Turn on the vacuum pump
        PUMP_ON
        # 5. Wait momentarily for vacuum pressure to stabilize
        G4 P{dwell_time}
        VALVE_ON
        G4 P{dwell_time} 
        # 6. Retract Z back to safe height with the component attached
        G1 Z{z_safe} F{speed_z}        
    {% endif %}

#Place Macro
[gcode_macro PLACE]
description: Moves to a specified X/Y coordinate, lowers, releases a component, and retracts.
gcode:
    # --- CONFIGURATION VARIABLES ---
    {% set z_safe = 80.0 %}      # Safe Z height for travel to avoid collisions
    {% set z_place = 20.0 %}      # Z height to place the component (adjust for your PCB/bed height)
    {% set target_z = params.Z|default(default_z_place)|float %}
    
    {% set speed_xy = 9000 %}    # XY travel speed (mm/min)
    {% set speed_z = 6000 %}     # Z plunge/retract speed (mm/min)
    {% set dwell_time = 500 %}   # Time to wait for vacuum to release (milliseconds)
    
    # --- INPUT PARAMETERS & SAFETY CHECK ---
    # Ensure both X and Y were provided in the command (e.g., PLACE X=150 Y=150)
    {% if 'X' not in params or 'Y' not in params %}
        { action_raise_error("Missing X or Y coordinates! Usage: PLACE X=[value] Y=[value]") }
    {% else %}
        
        # Parse the inputs as floats
        {% set target_x = params.X|float %}
        {% set target_y = params.Y|float %}
        
        G90
        G1 Z{z_safe} F{speed_z}       
        G1 X{target_x} F{speed_xy}
        G1 Y{target_y} F{speed_xy}
        G1 Z{target_z} F{speed_z}
        PUMP_OFF
        G4 P{dwell_time}
        VALVE_OFF
        G4 P{dwell_time} 
        G1 Z{z_safe} F{speed_z}
    {% endif %}
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

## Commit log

2025-10-15 I've been forgetting to push changes, a lot of nonsense here, but this is the first version that compiles sucessfully. Oh, and it's missing the soleniod control at the moment.
    [ConfigurationNEW.h, Configuration_adv.h]
2025-10-20 games, custom bootscreen, other minor changes
    [Configuration_adv.h]
2025-10-23 enabled direct pin control, have config in UI but doesn't work, need to dig into custom main menu settings
    [Configuration_adv.h]
2025-10-30 relays are not relaying
    [Configuration.h, Configuration_adv.h]
2025-11-04 switched to fan headers for pump control, changed bootscreen image
    [Configuration.h, Configuration_adv.h]
2025-11-09 STEP Assembly and Printable Features
    [Adapter.STL, BasePlate.STL, Center_No_Solenoid.STEP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]
2025-11-09 Update Read Me.md
    printing instructions format fix
2025-11-09 Added PushPullFeeder
    Our modified feeder that works with 4040 extrusion
    [PushPullFeeder.scad, PushPullFeeder_PH1.stl, PushPullFeeder_PH2.stl]
2025-11-10 sundays updates
    [Configuration.h, Configuration_adv.h]
2025-11-13 updated values for z to match x,y added 2nd extruder (untested), added custom homing menu to hmi
    [Configuration.h]
2026-03-29 V2 Prep
    [Adapter.STL, BasePlate.STL, Center_No_Solenoid.STEP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]
2026-04-15 loading cad and media
    [36Gear.step, 8Gear.step, BOT_leg.step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]
2026-04-15 CAD updates
    update documentation and added pneumatic parts
    [BackFrontPanel.STEP, Baseplate.STEP, Sidepanel.STEP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]
2026-04-16 added Klipper stuff
    [printer.cfg]
2026-04-16 Additional renders and fixed missing assembly pieces
    Added the clamping mechanism to the master assembly which was missing originally. Created additional renders and tweaking readme's
2026-04-16 Bill of Material Compilation
    sourced from Google Sheets
    [Frame Assembly.csv, Framing Material.csv, Hardware.csv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]
2026-04-20 Finalized all V2 BOMs and new images
    [Electrical Enclosure.csv, Framing Material.csv, Hardware List.csv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]
2026-10-25 Update camera config and feeder rib
    To match toolhead rotation motor and to make it easier to position the rib alignment
2026-11-08 Camera Calibration
    The calibrater script is done and programmed for Charuco boards and the down camera. Integration to show a preview of the undistorted display with Mainsail handled with new undistort_stream.py
2026-11-08 Update readme
    Removing old capture pictures, updating readme to reflect current calibrate pipeline
2026-11-08 Calibrate Complete and new Lighting Macros
    Finished calibrating the up and down cameras, synced with Mainsail dashboard. Added down camera light toggle macros. Laid out the vision pipeline. Updated Readmes.
2026-11-08 Square-pixel undistortion for pnpvision
    Fixes for calibration circle showing as an oval by down camera
2026-11-08 Add optical reticle px to mm to undistort_stream
    Added a crosshair to camera undistort stream (mainsail)
2026-11-08 Add down camera repeatability test
    Vision pipeline repeatability test calib stage
2026-11-09 Add visual homing on datum dot 0
    Setup visual homing on datum dot 0 and ran into some repeat issues on sensorless homing as of now
2026-11-09 Datum pose from dot center detection
    Because of down camera height sensitivity, visually identify datum dots from grid teach based on visual center
2026-11-09 Add job file spec and generator handoff
    For board to gcode/job slicer
2026-11-09 Up-camera ring light on PG13
    Disabled feeder servo for now
2026-11-10 Up camera ring on EXP1_8
    Trying to put the up camera lights on LCD header
2026-11-10 Checklist: up-camera ring working on EXP1
2026-11-10 up camera jog calibration
    finds dots and stuff
2026-11-11 up cam and update offsets for nozzle remount
2026-11-11 nozzle remount recovery
    hate gantry bruh
2026-11-11 place test find parts before and after images
    reject empty nozzle
2026-11-11 robust landing check on place sim
2026-11-11 board alignment from job
2026-11-11 board alignment, test pcb job, place test angle sweep
2026-11-11 board alignment test pcb job angle sweep
2026-11-12 place onto board footprints verified
2026-11-12 job runner prototype including feeders, tips, nano firmware
2026-11-14 Uno R3 as second Klipper MCU, up light on uno:PB3, crowsnest exposure lock

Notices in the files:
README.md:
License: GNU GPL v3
